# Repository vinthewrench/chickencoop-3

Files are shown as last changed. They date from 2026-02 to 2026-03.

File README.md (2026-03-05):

# Chicken Coop Controller 3.0

**Build your own automated, off-grid chicken coop door**

A minimal, ultra-reliable, battery-powered AVR controller that opens the door at sunrise, closes and locks it at sunset — completely offline, no sensors, no Wi-Fi, no cloud, no GPS.

Designed for a mobile pasture-raised coop that moves with cattle and sheep. Runs for months on a small 12 V battery (solar is only a top-up). Survives Arkansas mud, ice, dust, coyotes, and power failures.

Full 18-page design story, sunrise math, and lessons learned here:  
https://www.vinthewrench.com/<update this>

### Features

- True sunrise/sunset calculation using location + date (NO light sensor)
- Gravity-hung door with Progressive Automations PA-14 actuator
- Automatic locking bar (automotive-style actuator) to stop predators
- Manual override button with bi-color LED status
- Ultra-low sleep current (~355 µA) → months on a 7–22 Ah SLA/AGM battery
- One-time setup via serial console (no phone app or internet required)
- Two extra latching relays for electric fence or lights (zero holding current)
- Handles power failures, manual overrides, and reboots correctly
- Fully open-source (firmware + schematics + PCB)

### Licenses

- Firmware: MIT
- Hardware (schematics + PCB): CERN-OHL-P v2

You are free to study, modify, and build your own.

---

## How It Works

1. The DS3231M RTC wakes the ATmega1284P at the next event (sunrise or sunset).
2. Firmware calculates exact sunrise/sunset from latitude, longitude, and date.
3. If needed, it drives the door actuator and lock.
4. It sets the next alarm and goes back to deep sleep.

No drift, no false triggers from clouds, headlights, or moving the coop.

Manual button press overrides the schedule until the next natural event (sunrise/sunset). The system never fights you.

---

## Hardware

Custom 100 × 130 mm PCB (all through-hole friendly where possible).

### Major Components

| Component | Part | Notes |
| --- | --- | --- |
| MCU | ATmega1284P-PU (DIP-40) | 128 KB flash, easy ISP, repairable |
| RTC | DS3231M | Integrated resonator, temperature compensated |
| Door Actuator | Progressive Automations PA-14 | IP65, internal limits, stainless rod |
| Lock Actuator | 12 V automotive door lock | Pulses only (200–300 ms) |
| Motor Drivers | 2 × VNH7100BAS | 15 A H-bridges with thermal copper pours |
| 5 V Regulator | Pololu D24V22F5 | High efficiency, low quiescent current |
| Button | Illuminated bi-color switch | Red/Green status + override |
| Relays | 2 × DSP1-L2-DC12V | Latching (zero holding current) |
| Relay Driver | ULN2003A | Drives relays + optional loads |
| Optional Console | SparkFun DEV-15096 | USB-to-serial for setup (removable) |

Power: Single 12 V battery (SLA/AGM recommended). Direct 12 V to motors, regulated 5 V for logic.

---

## Firmware

Written in plain C for avr-gcc. No Arduino framework, no hidden magic.

Typical workflow:

```bash
cd firmware
make set-fuses
make
make flash          # or use your programmer
```

Full build system, clean targets, and EEPROM config handling included.

---

## Setup & Configuration

1. Flip the **CONFIG switch** to ON (this puts the controller into console mode).
2. Connect the optional SparkFun USB-to-serial module (or any 5 V TTL serial).
3. Open a terminal (38400 baud).
4. Set date/time, latitude, longitude, timezone offset, and schedule offsets.
5. Flip the **CONFIG switch** back to OFF when done.
6. Remove the module — the controller no longer needs it.

All settings stored in EEPROM. No re-configuration unless you move to a new location.

---

## Using the CONFIG Switch & Console

The physical **CONFIG switch** on the board toggles between normal low-power run mode and console configuration mode. When flipped to ON, the MCU stays awake, enables the serial console, and allows full setup/debug without sleeping. Flip back to OFF to resume automatic scheduling and deep sleep.

**Configuration steps:**

1. Flip CONFIG to ON.
2. Connect serial (38400 baud) and type commands.
3. Use `set` to configure, `event add` for schedules, `save` to commit.
4. Flip CONFIG to OFF.

**What you need to set (minimum for basic operation):**

- Date and time (`set date YYYY-MM-DD`, `set time HH:MM[:SS]`)
- Location (`set lat +/-DD.DDDD`, `set lon +/-DDD.DDDD`)
- Timezone (`set tz +/-HH`, `set dst on|off`)
- Events (`event add door on sunrise +0`, `event add door off sunset -15`, etc. for lock/relays)

**Key commands:**
| Command | What it does |
|---|---|
| `help` | List all commands |
| `config` | Show current settings |
| `set date YYYY-MM-DD` | Set date |
| `set time HH:MM[:SS]` | Set time (local) |
| `set lat +/-DD.DDDD` | Set latitude |
| `set lon +/-DDD.DDDD` | Set longitude |
| `set tz +/-HH` | Set timezone offset |
| `set dst on\|off` | Enable/disable DST |
| `event add ...` | Add door open/close events (sunrise/sunset or fixed time) |
| `save` | Commit everything to EEPROM |
| `schedule` | Show today’s full schedule |
| `solar` | Show sunrise/sunset |
| `door open\|close\|toggle` | Manual door test |
| `lock engage\|release` | Manual lock test |

Type `help` for full list. Changes are RAM-only until `save`.

---

## Repository Contents

- /firmware/ — AVR source + Makefile
- /hardware/ — KiCad schematics + PCB layout

---

## Typical Daily Workflow (after initial setup)

The controller just works. You walk out once a day to collect eggs.

---

## Links & Resources

- Full article: https://www.vinthewrench.com/<update>
- Buy the exact actuator: Progressive Automations PA-14 (PA-01-12-56-N-12VDC model)

Questions? Open an issue or find me on X @vinthewrench.

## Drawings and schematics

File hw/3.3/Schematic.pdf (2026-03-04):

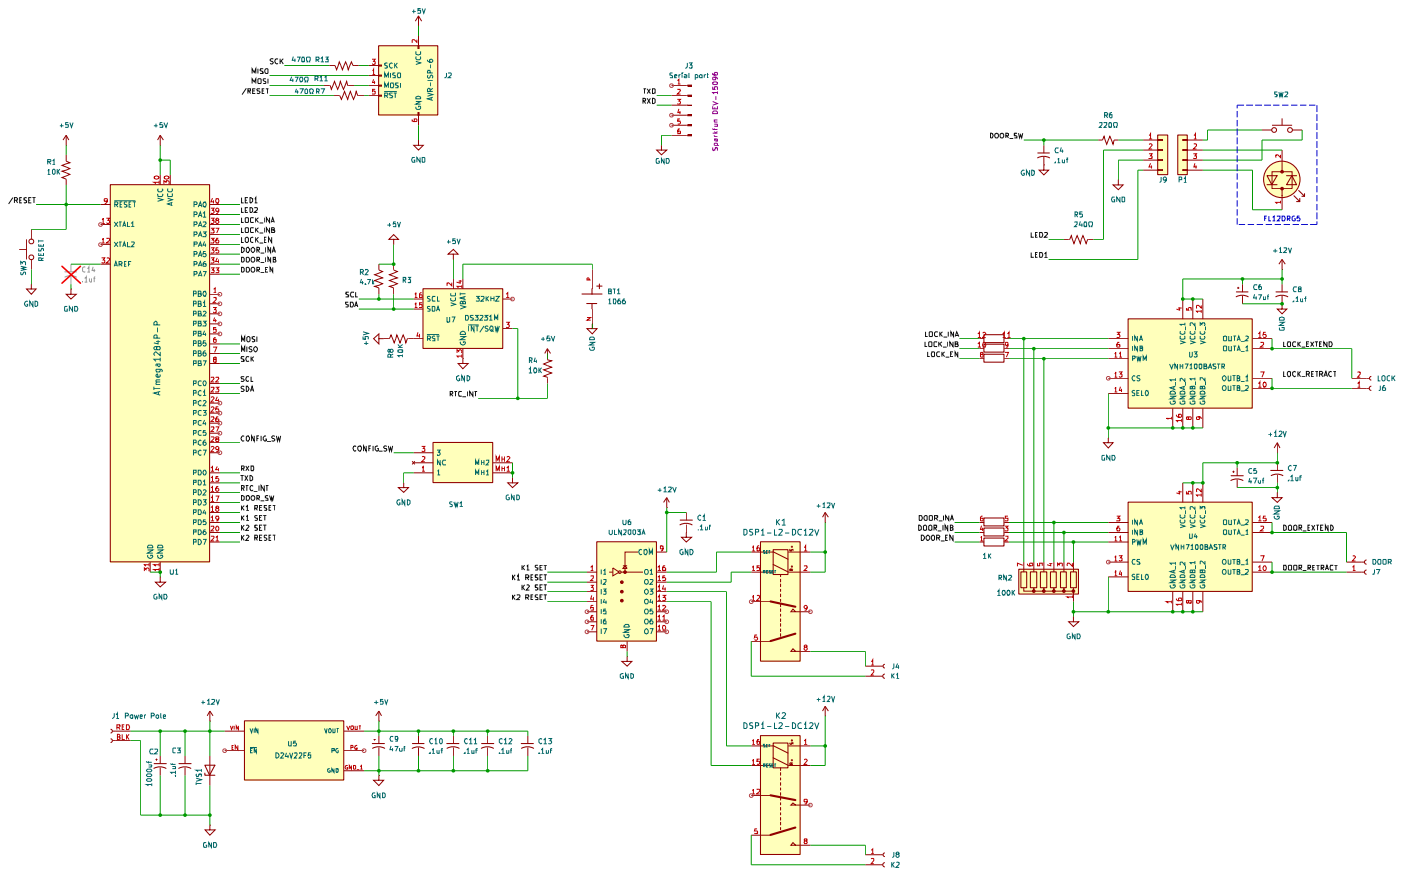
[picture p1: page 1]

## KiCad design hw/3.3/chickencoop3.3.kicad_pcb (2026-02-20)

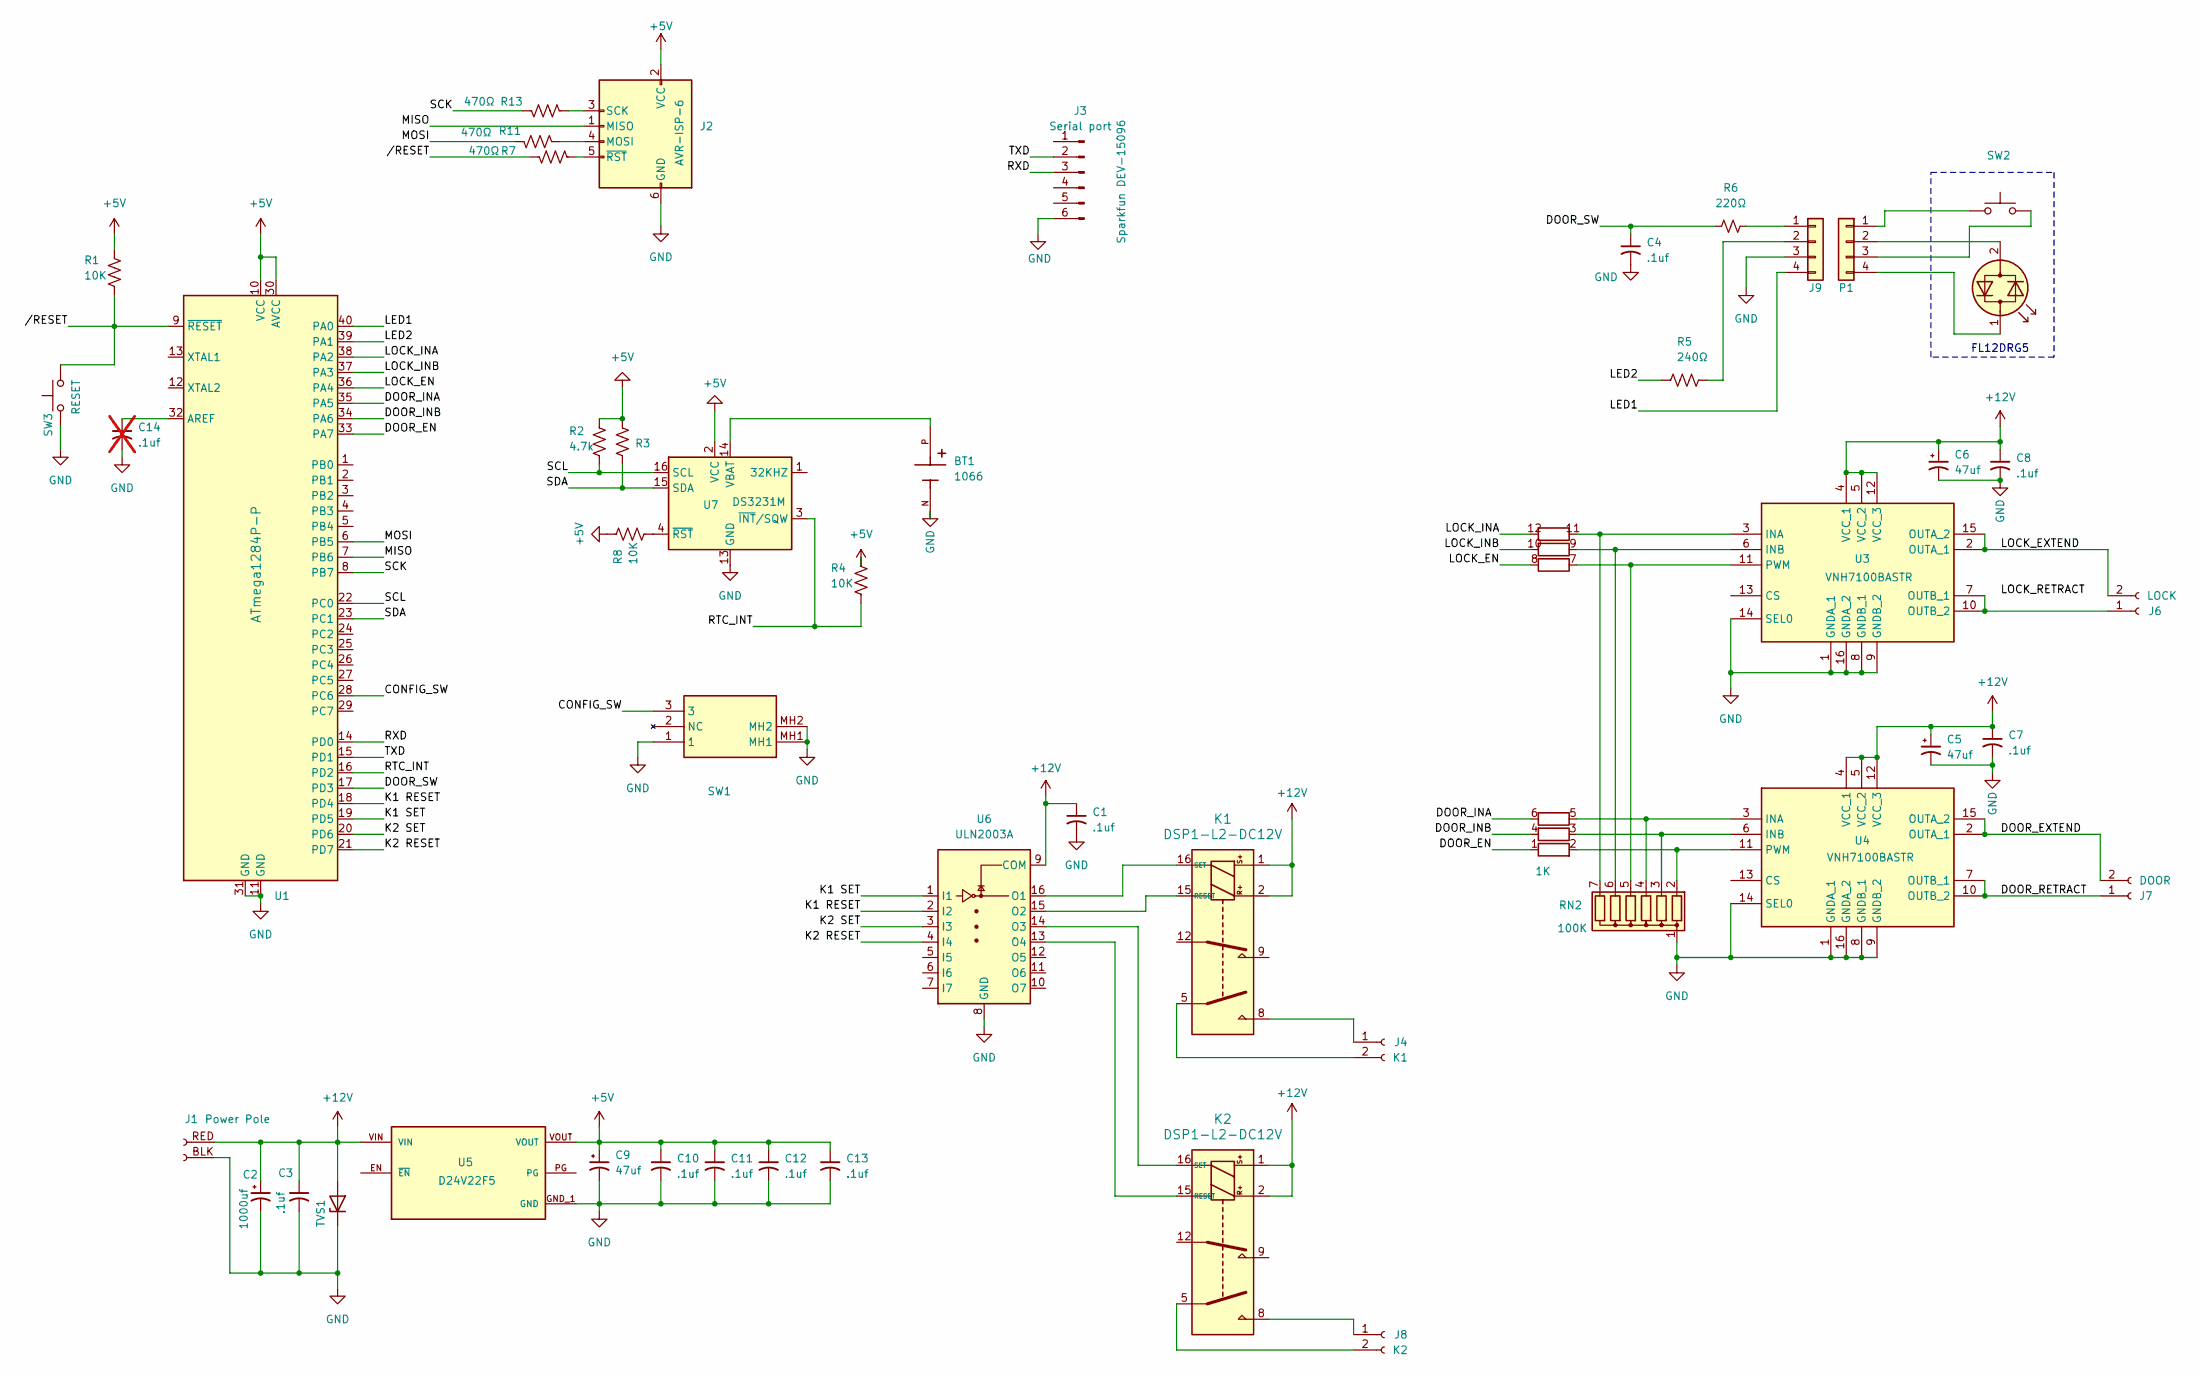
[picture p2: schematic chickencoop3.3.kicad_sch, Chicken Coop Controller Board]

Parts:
BT1: 1066; BAT_1066; PARTREV E
C1, C3, C4, C7, C8, C10, C11, C12, C13: .1uf; RCER71H104K0DBH03A
C2: 1000uf; CP_Radial_D10.0mm_P5.00mm
C5, C6, C9: 47uf; CP_Radial_D5.0mm_P2.00mm
C14: .1uf; RCER71H104K0DBH03A; not fitted
D1: LED_Dual_Bidirectional
J1: Power Pole; powerpole
J2: AVR-ISP-6; PinHeader_2x03_P2.54mm_Vertical
J3: Serial port; PinHeader_1x06_P2.54mm_Vertical
J4: K1; TerminalBlock_Phoenix_MKDS-1,5-2-5.08_1x02_P5.08mm_Horizont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
J6: LOCK; TerminalBlock_Phoenix_MKDS-1,5-2-5.08_1x02_P5.08mm_Horizont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
J7: DOOR; TerminalBlock_Phoenix_MKDS-1,5-2-5.08_1x02_P5.08mm_Horizont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
J8: K2; TerminalBlock_Phoenix_MKDS-1,5-2-5.08_1x02_P5.08mm_Horizont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
J9: Mini‑Fit Jr; Molex_Mini-Fit_Jr_5566-04A_2x02_P4.20mm_Vertical
K1, K2: DSP1-L2-DC12V
P1: Mini‑Fit Jr; Molex_Mini-Fit_Jr_5566-04A_2x02_P4.20mm_Vertical
R1, R4, R8: 10K; R_Axial_DIN0204_L3.6mm_D1.6mm_P7.62mm_Horizontal
R2: 4.7k; R_Axial_DIN0204_L3.6mm_D1.6mm_P7.62mm_Horizontal
R3: 4.7K; R_Axial_DIN0204_L3.6mm_D1.6mm_P7.62mm_Horizontal
R5: 240Ω; R_Axial_DIN0204_L3.6mm_D1.6mm_P7.62mm_Horizontal
R6: 220Ω; R_Axial_DIN0204_L3.6mm_D1.6mm_P7.62mm_Horizontal
R7, R11, R13: 470Ω; R_Axial_DIN0204_L3.6mm_D1.6mm_P7.62mm_Horizontal
RN2: 100K; R_Array_SIP7; Manufacturer_Part_Number 4607X-101-104LF
RN4: 1K; R_Array_SIP12; Manufacturer_Part_Number 4612X-102-102LF
SW1: SW_SPST; AS11CH; Mouser Part Number 633-AS11CH
SW2: SW_Push
SW3: RESET; SW_PUSH_6mm
TVS1: P6SMB18A; D_SMB_Handsoldering
U1: ATmega1284P-P; DIP-40_W15.24mm
U3, U4: VNH7100BASTR; SOIC127P600X175-16N; Manufacturer_Part_Number VNH7100BASTR; Mouser Part Number 511-VNH7100BASTR
U5: D24V22F5; MODULE_5V_2.5A_STEP-DOWN_D24V22F5; PARTREV 12 November 2015
U6: ULN2003A; DIP-16_W7.62mm
U7: DS3231M; SOIC-16W_7.5x10.3mm_P1.27mm

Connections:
+5V: C9.1, C10.1, C11.1, C12.1, C13.1, J2.2 (VCC), R1.1, R2.1, R3.1, R4.1, R8.1, U1.10 (VCC), U1.30 (AVCC), U5.VOUT, U7.2 (VCC)
+12V: C1.1, C2.1, C3.1, C5.1, C6.1, C7.1, C8.1, J1.RED, K1.1, K1.2, K2.1, K2.2, TVS1.2 (A), U3.4 (VCC_1), U3.5 (VCC_2), U3.12 (VCC_3), U4.4 (VCC_1), U4.5 (VCC_2), U4.12 (VCC_3), U5.VIN, U6.9 (COM)
/CONFIG_SW: SW1.3, U1.28 (PC6)
/DOOR_EN: RN4.1 (R1.1), U1.33 (PA7)
/DOOR_EXTEND: J7.2, U4.2 (OUTA_1), U4.15 (OUTA_2)
/DOOR_INA: RN4.6 (R3.2), U1.35 (PA5)
/DOOR_INB: RN4.4 (R2.2), U1.34 (PA6)
/DOOR_RETRACT: J7.1, U4.7 (OUTB_1), U4.10 (OUTB_2)
/DOOR_SW: C4.1, R6.1, U1.17 (PD3)
/K1 RESET: U1.18 (PD4), U6.2 (I2)
/K1 SET: U1.19 (PD5), U6.1 (I1)
/K2 RESET: U1.21 (PD7), U6.4 (I4)
/K2 SET: U1.20 (PD6), U6.3 (I3)
/LED1: J9.4, U1.40 (PA0)
/LED2: R5.1, U1.39 (PA1)
/LOCK_EN: RN4.8 (R4.2), U1.36 (PA4)
/LOCK_EXTEND: J6.2, U3.2 (OUTA_1), U3.15 (OUTA_2)
/LOCK_INA: RN4.12 (R6.2), U1.38 (PA2)
/LOCK_INB: RN4.10 (R5.2), U1.37 (PA3)
/MISO: J2.1 (MISO), U1.7 (PB6)
/MOSI: R11.1, U1.6 (PB5)
/RTC_INT: R4.2, U1.16 (PD2), U7.3 (~INT/SQW)
/RXD: J3.3, U1.14 (PD0)
/SCK: R13.1, U1.8 (PB7)
/SCL: R2.2, U1.22 (PC0), U7.16 (SCL)
/SDA: R3.2, U1.23 (PC1), U7.15 (SDA)
/TXD: J3.2, U1.15 (PD1)
//RESET: R1.2, R7.1, SW3.2, U1.9 (~RESET)
GND: BT1.N, C1.2, C2.2, C3.2, C4.2, C5.2, C6.2, C7.2, C8.2, C9.2, C10.2, C11.2, C12.2, C13.2, C14.2, J1.BLK, J2.6 (GND), J3.6, J9.3, RN2.1 (common), SW1.1, SW1.MH1, SW1.MH2, SW3.1, TVS1.1 (K), U1.11 (GND), U1.31 (GND), U3.1 (GNDA_1), U3.8 (GNDB_1), U3.9 (GNDB_2), U3.14 (SEL0), U3.16 (GNDA_2), U4.1 (GNDA_1), U4.8 (GNDB_1), U4.9 (GNDB_2), U4.14 (SEL0), U4.16 (GNDA_2), U5.GND_1 (GND), U5.GND_2 (GND), U6.8 (GND), U7.5 (GND), U7.6 (GND), U7.7 (GND), U7.8 (GND), U7.9 (GND), U7.10 (GND), U7.11 (GND), U7.12 (GND), U7.13 (GND)
unnamed: D1.1 (KA), P1.4
unnamed: D1.2 (AK), P1.2
unnamed: J2.4 (MOSI), R11.2
unnamed: J2.3 (SCK), R13.2
unnamed: J2.5 (~RST), R7.2
unnamed: J4.1, K1.8
unnamed: J4.2, K1.5
unnamed: J6.1, U3.7 (OUTB_1), U3.10 (OUTB_2)
unnamed: J8.1, K2.8
unnamed: J8.2, K2.5
unnamed: J9.1, R6.2
unnamed: J9.2, R5.2
unnamed: K1.15 (RESET), U6.15 (O2)
unnamed: K1.16 (SET), U6.16 (O1)
unnamed: K2.15 (RESET), U6.13 (O4)
unnamed: K2.16 (SET), U6.14 (O3)
unnamed: P1.1, SW2.1
unnamed: P1.3, SW2.2
unnamed: RN2.2 (R1), RN4.2 (R1.2), U4.11 (PWM)
unnamed: RN2.3 (R2), RN4.3 (R2.1), U4.6 (INB)
unnamed: RN2.4 (R3), RN4.5 (R3.1), U4.3 (INA)
unnamed: RN2.5 (R4), RN4.7 (R4.1), U3.11 (PWM)
unnamed: RN2.6 (R5), RN4.9 (R5.1), U3.6 (INB)
unnamed: RN2.7 (R6), RN4.11 (R6.1), U3.3 (INA)
unnamed: C14.1, U1.32 (AREF)
unnamed: BT1.P, U7.14 (VBAT)
unnamed: R8.2, U7.4 (~RST)

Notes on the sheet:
FL12DRG5

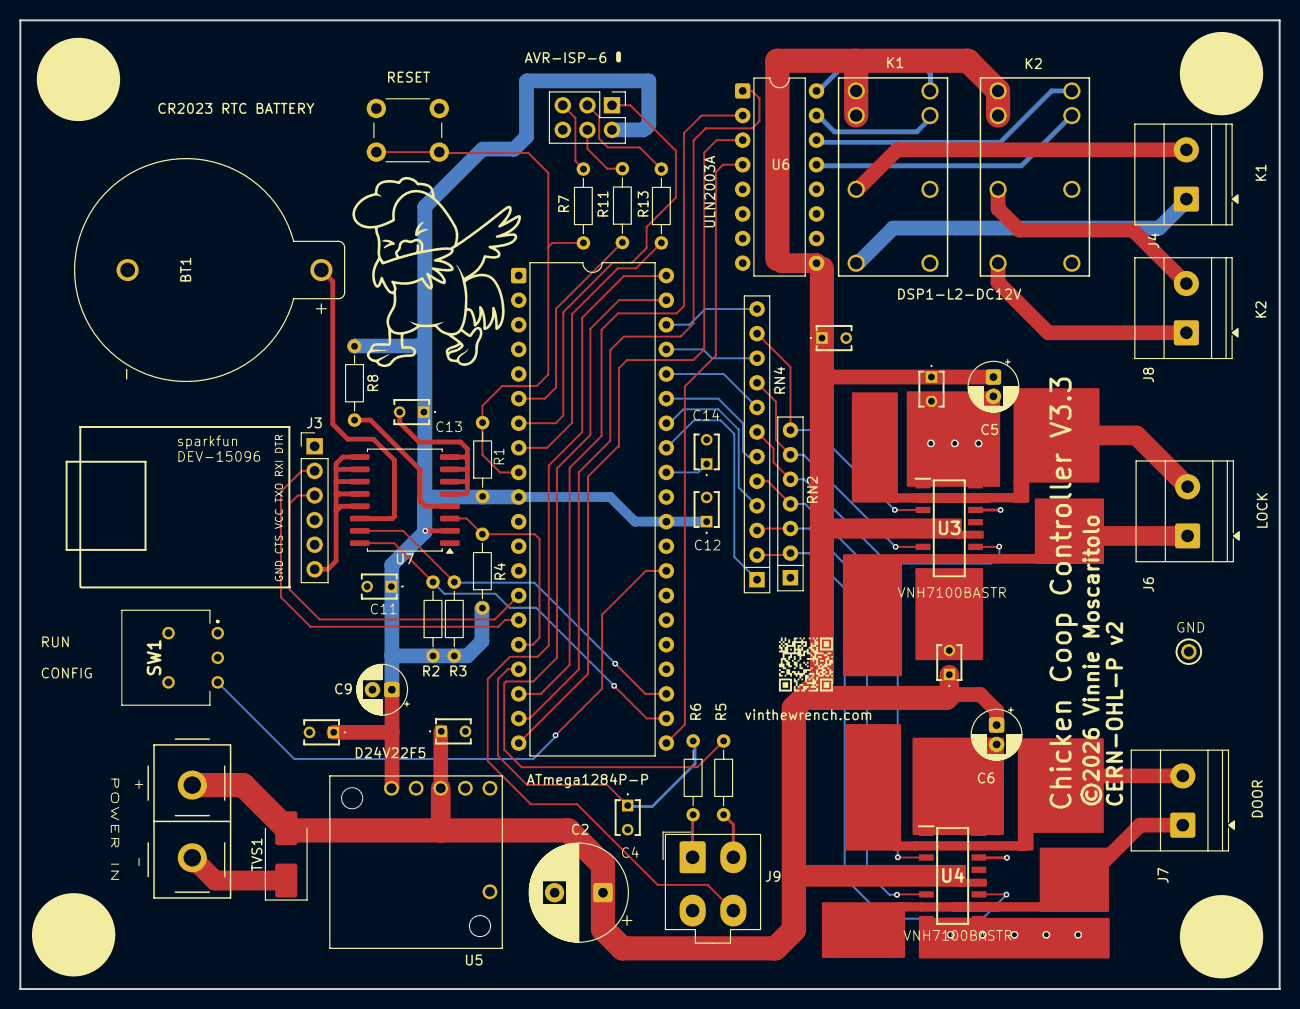
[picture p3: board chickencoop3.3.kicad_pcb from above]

Board: 2 copper layers, 130.0 x 100.0 mm, 47 parts (0 on the bottom side), 52 nets.

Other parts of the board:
TP3: GND; 5000

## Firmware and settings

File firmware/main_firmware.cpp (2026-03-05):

/*
 * main_firmware.cpp
 *
 * Chicken Coop Controller
 *
 * WAKE TRUTH:
 *   RTC INT → PD2 (INT0)
 *   LOW-level trigger
 *   SLEEP_MODE_PWR_DOWN
 *
 * Anything else is wrong.
 *
 * Time Model (UPDATED):
 *   - RTC returns UTC.
 *   - Scheduler runs in UTC.
 *   - Solar compute is requested in UTC (tz = 0).
 *   - TZ/DST must NOT affect scheduling here.
 *   - TZ/DST are console/UI concerns only.
 *
 * Updated: 2026-02-16
 */

#include <stdbool.h>
#include <stdint.h>
#include <util/delay.h>
#include <avr/io.h>
#include <avr/wdt.h>
#include <avr/interrupt.h>

#include "config.h"
#include "config_sw.h"

#include "console/console.h"
#include "console/mini_printf.h"

#include "uptime.h"
#include "rtc.h"
#include "solar.h"
#include "platform/uart.h"
#include "system_sleep.h"

/* DST/TZ must not be used for scheduling here. */
// #include "time_dst.h"

#include "scheduler.h"
#include "state_reducer.h"
#include "schedule_apply.h"

#include "devices/devices.h"
#include "devices/led_state_machine.h"
#include "devices/door_state_machine.h"

#include "platform/gpio_avr.h"
#include "platform/i2c.h"


/* ============================================================================
 * INT0 WAKE (PD2)
 * ========================================================================== */

ISR(INT0_vect)
{
    EIMSK &= (uint8_t)~(1u << INT0);
}

static volatile uint8_t g_door_event = 0;

ISR(INT1_vect)
{
    EIMSK &= (uint8_t)~(1u << INT1);
    g_door_event = 1u;
}


/* ============================================================================
 * TIME HELPERS
 * ========================================================================== */

static inline uint16_t minute_of_day(int h, int m)
{
    return (uint16_t)((uint16_t)h * 60u + (uint16_t)m);
}

static inline uint16_t next_minute(uint16_t now_min)
{
    return (uint16_t)((now_min + 1u) % 1440u);
}

static inline uint16_t strictly_future_minute(uint16_t now_min,
                                              uint16_t target_min)
{
    if (target_min <= now_min)
        return next_minute(now_min);
    return target_min;
}


/* ============================================================================
 * RESET CAUSE
 * ========================================================================== */

static uint8_t g_reset_flags;

static void reset_cause_capture_early(void)
{
    g_reset_flags = MCUSR;
    MCUSR = 0;
    wdt_disable();

    MCUCR |= _BV(JTD);
    MCUCR |= _BV(JTD);
}

static void reset_cause_debug_print(void)
{
    if (g_reset_flags & _BV(PORF))  mini_printf("RESET: Power On\n");
    if (g_reset_flags & _BV(BORF))  mini_printf("RESET: Brown-Out\n");
    if (g_reset_flags & _BV(WDRF))  mini_printf("RESET: Watchdog\n");
}


/* ============================================================================
 * MAIN
 * ========================================================================== */

int main(void)
{
    bool rtc_valid = false;

    reset_cause_capture_early();

    if (g_reset_flags & _BV(BORF)) {
        _delay_ms(50);
    }

    uart_init();
    uptime_init();
    coop_gpio_init();

    if (!i2c_init(100000)) {
        led_state_machine_init();
        led_state_machine_set(LED_BLINK, LED_RED);
        for (;;) {
            led_state_machine_tick(uptime_millis());
        }
    }

    rtc_init();

    rtc_valid = rtc_validate_at_boot();

    system_sleep_init();
    sei();

    device_init();
    scheduler_init();
    (void)config_load(&g_cfg);

    led_state_machine_set(LED_BLINK, LED_GREEN, 4);

    int last_y  = -1;
    int last_mo = -1;
    int last_d  = -1;

    uint16_t last_minute = 0xFFFF;
    uint32_t last_etag   = 0;

    struct solar_times sol;
    bool have_sol = false;

    bool in_config_mode = false;

    uint8_t  door_debounce_active   = 0;
    uint32_t door_debounce_start_ms = 0;

    int cached_y = 0, cached_mo = 0, cached_d = 0;
    int cached_h = 0, cached_m = 0, cached_s = 0;

    for (;;) {

        uint32_t now_ms = uptime_millis();
        device_tick(now_ms);

        /* ------------------------------------------------------
         * CONFIG switch
         * ------------------------------------------------------ */

        bool raw = config_sw_state();

        if (raw != in_config_mode) {

            _delay_ms(75);

            if (config_sw_state() == raw) {

                in_config_mode = raw;

                if (in_config_mode) {
                    console_init();
                    reset_cause_debug_print();
                } else {
                    mini_printf("Exiting console\n\n");
                    console_flush();
                    console_terminal_shutdown();
                }
            }
        }

        if (in_config_mode) {
            console_poll();
        }

        /* ------------------------------------------------------
         * Door ISR latch
         * ------------------------------------------------------ */

        if (g_door_event && !door_debounce_active) {
            g_door_event = 0u;
            door_debounce_active = 1u;
            door_debounce_start_ms = now_ms;
        }

        if (door_debounce_active) {
            if ((uint32_t)(now_ms - door_debounce_start_ms) >= 20u) {
                door_debounce_active = 0u;
                if (gpio_door_sw_is_asserted()) {
                    door_sm_toggle();
                }
            }
        }

        if (!gpio_door_sw_is_asserted() && !door_debounce_active) {
            EIFR  |= (uint8_t)(1u << INTF1);
            EIMSK |= (uint8_t)(1u << INT1);
        }

        /* ------------------------------------------------------
         * RTC required
         * ------------------------------------------------------ */

        if (rtc_time_is_set()) {
            if (!rtc_valid) rtc_valid = true;
        }
        else
        {
            led_state_machine_set(LED_BLINK, LED_RED);
            continue;
        }

        /* ------------------------------------------------------
         * Always refresh RTC (UTC authoritative)
         * ------------------------------------------------------ */

        rtc_get_time(&cached_y,
                     &cached_mo,
                     &cached_d,
                     &cached_h,
                     &cached_m,
                     &cached_s);

        uint16_t now_minute = minute_of_day(cached_h, cached_m);
        uint32_t cur_etag   = schedule_etag();

        bool minute_changed = (now_minute != last_minute);
        bool schedule_dirty = (cur_etag != last_etag);

        /* ------------------------------------------------------
         * On minute change or schedule change, run scheduler
         * ------------------------------------------------------ */

        if (minute_changed || schedule_dirty) {

            last_minute = now_minute;
            last_etag   = cur_etag;

            /* ---- Solar recompute if date changed ---- */

            if (cached_y != last_y ||
                cached_mo != last_mo ||
                cached_d != last_d) {

                have_sol = false;

                if (g_cfg.latitude_e4 != 0 ||
                    g_cfg.longitude_e4 != 0) {

                    double lat = (double)g_cfg.latitude_e4  / 10000.0;
                    double lon = (double)g_cfg.longitude_e4 / 10000.0;

                    /*
                     * Scheduling must be DST-invariant.
                     *
                     * Request solar times in UTC by forcing tz = 0.
                     * (Any TZ/DST adjustments belong in console/UI only.)
                     */
                    have_sol = solar_compute(
                        cached_y, cached_mo, cached_d,
                        lat, lon,
                        0,
                        &sol
                    );
                }

                scheduler_update_day(
                    cached_y, cached_mo, cached_d,
                    have_sol ? &sol : NULL,
                    have_sol
                );

                last_y  = cached_y;
                last_mo = cached_mo;
                last_d  = cached_d;
            }

            uint32_t midnight_epoch =
                rtc_epoch_from_ymdhms(
                    cached_y,
                    cached_mo,
                    cached_d,
                    0, 0, 0,
                    0,
                    false
                );

            /* ---- Apply schedule ---- */

            struct reduced_state rs;

            size_t used = 0;
            const Event *events = config_events_get(&used);

            if (events && used > 0) {

                state_reducer_run(
                    events,
                    MAX_EVENTS,
                    have_sol ? &sol : NULL,
                    now_minute,
                    midnight_epoch,
                    &rs
                );

                schedule_apply(&rs);
            }
        }

        /* ------------------------------------------------------
         * Sleep only in RUN mode
         * ------------------------------------------------------ */

        if (in_config_mode)
            continue;

        if (devices_busy() ||
            door_debounce_active ||
            g_door_event)
            continue;

        uint16_t next_min;
        uint16_t wake_min;

        if (scheduler_next_event_minute(now_minute, &next_min))
            wake_min = next_min;
        else
            wake_min = next_minute(now_minute);

        (void)rtc_alarm_set_minute_of_day(wake_min);
        system_sleep_until(wake_min);

        if (gpio_rtc_int_is_asserted())
            rtc_alarm_clear_flag();

        EIFR |= (uint8_t)((1u << INTF0) | (1u << INTF1));

        if (!gpio_rtc_int_is_asserted())
            EIMSK |= (uint8_t)(1u << INT0);

        if (!gpio_door_sw_is_asserted())
            EIMSK |= (uint8_t)(1u << INT1);
    }
}

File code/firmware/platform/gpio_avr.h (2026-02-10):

/*
 * gpio_avr.h
 *
 * Project: Chicken Coop Controller
 * Purpose: AVR GPIO pin definitions and low-level hardware mapping
 *
 * This header defines the canonical mapping between AVR GPIO pins
 * and physical hardware functions on the Chicken Coop Controller PCB.
 *
 * IMPORTANT DESIGN RULES:
 *  - All mappings in this file are LOCKED to the board schematic.
 *  - Do NOT rename, repurpose, or reassign any pin here unless
 *    the PCB schematic and layout are changed accordingly.
 *  - Higher-level code MUST treat these as hardware truth.
 *
 * SAFETY NOTE:
 *  - Several pins in this file control motors, relays, and solenoids.
 *  - Incorrect initialization or prolonged activation CAN damage hardware.
 *  - All outputs must be initialized to a known-safe OFF state at boot.
 *
 * Updated:
 *   (fill in date when pin mapping changes — not for code-only edits)
 */

#pragma once

/* --------------------------------------------------------------------------
 * Status LED Outputs
 * --------------------------------------------------------------------------
 *
 * These pins drive the front-panel red/green status LED through
 * external driver hardware.
 *
 * Naming convention:
 *  - LED_IN1 / LED_IN2 match the schematic net names.
 *  - Color association is documented for human clarity only.
 *
 * NOTE:
 *  - Do NOT change these names unless the hardware wiring changes.
 * -------------------------------------------------------------------------- */
 #define LED_IN1_BIT   PA1   /* RED   */
 #define LED_IN2_BIT   PA0   /* GREEN */

/* --------------------------------------------------------------------------
 * Door Motor H-Bridge Control (VNH7100BASTR)
 * --------------------------------------------------------------------------
 *
 * This H-bridge drives the main chicken coop door actuator.
 *
 * Electrical notes:
 *  - The door actuator includes internal end-of-travel limit switches.
 *  - Despite this, firmware MUST still enforce a maximum travel time
 *    as a fail-safe against wiring or switch failure.
 *
 * Pin behavior:
 *  - DOOR_EN   : Enables/disables the H-bridge (active HIGH)
 *  - DOOR_INA  : Direction control A
 *  - DOOR_INB  : Direction control B
 *
 * Reset behavior:
 *  - DOOR_EN MUST be driven LOW at boot.
 *  - INA/INB MUST be driven LOW at boot.
 *
 * -------------------------------------------------------------------------- */
/* DOOR_INA -> PF5 (physical pin 38) */
/* DOOR_INB -> PF6 (physical pin 37) */
/* DOOR_EN  -> PF7 (physical pin 36) */
#define DOOR_INA_BIT   PA5
#define DOOR_INB_BIT   PA6
#define DOOR_EN_BIT    PA7

/* --------------------------------------------------------------------------
 * Door Lock Actuator H-Bridge (VNH7100BASTR)
 * --------------------------------------------------------------------------
 *
 * This H-bridge drives the door LOCK actuator.
 *
 * CRITICAL SAFETY WARNING:
 *  - The lock actuator does NOT have end-of-travel limit switches.
 *  - It MUST be driven using a SHORT, FIXED-DURATION PULSE ONLY.
 *  - Continuous drive WILL overheat and destroy the actuator.
 *
 * Firmware requirements:
 *  - LOCK_EN MUST never be left asserted continuously.
 *  - A hard maximum pulse time (lock_pulse_ms) is mandatory.
 *  - Lock control must be edge-triggered, not state-held.
 *
 * JTAG NOTE:
 *  - LOCK_EN uses PF4, which is a JTAG pin by default.
 *  - Runtime JTAG disable is REQUIRED before driving this pin.
 * -------------------------------------------------------------------------- */
/* LOCK_INA -> PF0 */
/* LOCK_INB -> PF1 */
/* LOCK_EN  -> PF4 */
#define LOCK_INA_BIT   PA2
#define LOCK_INB_BIT   PA3
#define LOCK_EN_BIT    PA4

/* --------------------------------------------------------------------------
 * Latching Relay Outputs
 * --------------------------------------------------------------------------
 *
 * These pins drive a dual latching relay via external driver circuitry.
 *
 * Relay behavior:
 *  - SET and RESET are separate coils.
 *  - Coils must be pulsed briefly; they must NOT be held energized.
 *
 * Firmware requirements:
 *  - All relay outputs must default to OFF at boot.
 *  - Pulse duration must be limited in software.
 * -------------------------------------------------------------------------- */
#define RELAY1_SET_BIT    PD5
#define RELAY1_RESET_BIT  PD4
#define RELAY2_SET_BIT    PD6
#define RELAY2_RESET_BIT  PD7
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

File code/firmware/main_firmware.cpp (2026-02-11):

/*
 * main_firmware.cpp
 *
 * Chicken Coop Controller
 *
 * WAKE TRUTH:
 *   RTC INT → PD2 (INT0)
 *   LOW-level trigger
 *   SLEEP_MODE_PWR_DOWN
 *
 * Anything else is wrong.
 *
 * Updated: 2026-02-08
 */

#include <stdbool.h>
#include <stdint.h>
#include <util/delay.h>
#include <avr/io.h>
#include <avr/wdt.h>
#include <avr/interrupt.h>

#include "config.h"
#include "config_sw.h"

#include "console/console.h"
#include "console/mini_printf.h"

#include "uptime.h"
#include "rtc.h"
#include "solar.h"
#include "platform/uart.h"
#include "system_sleep.h"

#include "time_dst.h"

#include "scheduler.h"
#include "state_reducer.h"
#include "schedule_apply.h"

#include "devices/devices.h"
#include "devices/led_state_machine.h"
#include "devices/door_state_machine.h"

#include "platform/gpio_avr.h"
#include "platform/i2c.h"


/* ============================================================================
 * INT0 WAKE (PD2)
 * ========================================================================== */
 /*
  * INT0 ISR
  *
  * One-shot mask so we don't re-enter while
  * RTC INT line is still held low (AF not cleared yet).
  */
 ISR(INT0_vect)
 {
     EIMSK &= (uint8_t)~(1u << INT0);
 }

 static volatile uint8_t g_door_event = 0;

 ISR(INT1_vect)
 {
     /* Mask INT1 immediately (one-shot) */
        EIMSK &= (uint8_t)~(1u << INT1);

        /* Latch event */
        g_door_event = 1u;
 }


// static void rtc_wake_init_pd2(void)
// {
//     /* PD2 input */
//     DDRD  &= (uint8_t)~(1u << PD2);

//     /* External pull-up exists. Leave internal OFF. */
//     PORTD &= (uint8_t)~(1u << PD2);

//     /* LOW-level trigger required for PWR_DOWN wake */
//     EICRA &= (uint8_t)~((1u << ISC01) | (1u << ISC00));

//     /* Clear any stale flag */
//     EIFR  |= (uint8_t)(1u << INTF0);

//     /* Enable INT0 */
//     EIMSK |= (uint8_t)(1u << INT0);
// }

/* ============================================================================
 * TIME HELPERS
 * ========================================================================== */

static inline uint16_t minute_of_day(int h, int m)
{
    return (uint16_t)((uint16_t)h * 60u + (uint16_t)m);
}

static inline uint16_t next_minute(uint16_t now_min)
{
    return (uint16_t)((now_min + 1u) % 1440u);
}

static inline uint16_t strictly_future_minute(uint16_t now_min,
                                              uint16_t target_min)
{
    if (target_min <= now_min)
        return next_minute(now_min);
    return target_min;
}



static uint8_t g_reset_flags;

static void reset_cause_capture_early(void)
{
    g_reset_flags = MCUSR;
    MCUSR = 0;          /* clear flags immediately */
    wdt_disable();      /* if WDT ever enabled, keep boot deterministic */

    /* Disable JTAG immediately (double write required) */
    MCUCR |= _BV(JTD);
    MCUCR |= _BV(JTD);

}

static void reset_cause_debug_print(void)
{
    /* Optional, but useful while you are validating BOD behavior */
     if (g_reset_flags & _BV(PORF))  mini_printf("RESET: Power On\n");
//    if (g_reset_flags & _BV(EXTRF)) mini_printf(" EXT");
    if (g_reset_flags & _BV(BORF))  mini_printf("RESET: Brown-Out\n");
    if (g_reset_flags & _BV(WDRF))  mini_printf("RESET: Watchdog\n");
 }


/* ============================================================================
 * MAIN
 * ========================================================================== */

int main(void)
{
    reset_cause_capture_early();

     /* If brown-out reset, allow rails + peripherals to settle */
     if (g_reset_flags & _BV(BORF)) {
         _delay_ms(50);
     }


    uart_init();

    if (!i2c_init(100000)) {
        mini_printf("I2C init failed\n");
        while (1);
    }

    uptime_init();
    rtc_init();

    coop_gpio_init();

    /* INT0 wake path (PD2) */
    system_sleep_init();

    sei();

    device_init();
    scheduler_init();

    (void)config_load(&g_cfg);

    /* ----------------------------------------------------------
     * CONFIG MODE
     * ---------------------------------------------------------- */

    static bool config_consumed = false;

    if (config_sw_state() && !config_consumed) {

        config_consumed = true;

        console_init();

        reset_cause_debug_print();   /* <-- add this here */

        if (!rtc_time_is_set())
            led_state_machine_set(LED_BLINK, LED_RED);

        while (!console_should_exit()) {
            console_poll();
            device_tick(uptime_millis());


            ///-----------
            /* Re-arm INT1 only when door switch is released */
            EIFR |= (uint8_t)(1u << INTF1);
            if (!gpio_door_sw_is_asserted()) {
                EIMSK |= (uint8_t)(1u << INT1);
            }

            /* ------------------------------------------------------
             * Manual Door Switch Event
             * ------------------------------------------------------ */
            if (g_door_event) {

                g_door_event = 0u;

                /* Confirm switch still asserted (debounce) */
                _delay_ms(20);


                if (gpio_door_sw_is_asserted()) {
                   door_sm_toggle();
                }
            }

            ///---


        }
    }


    /* ----------------------------------------------------------
     * RUN MODE requires valid RTC
     * ---------------------------------------------------------- */
    if (!rtc_time_is_set()) {
        led_state_machine_set(LED_BLINK, LED_RED);
        for (;;) {
            device_tick(uptime_millis());
        }
    }



    /* Healthy boot pulse */
    led_state_machine_set(LED_ON, LED_GREEN);
    {
        uint32_t t0 = uptime_millis();
        while ((uint32_t)(uptime_millis() - t0) < 1000u)
            device_tick(uptime_millis());
    }
    led_state_machine_set(LED_OFF, LED_GREEN);

    /* ----------------------------------------------------------
     * Scheduler state
     * ---------------------------------------------------------- */
    uint16_t last_minute = 0xFFFF;
    uint32_t last_etag   = 0;

    int last_y  = -1;
    int last_mo = -1;
    int last_d  = -1;

    struct solar_times sol;
    bool have_sol = false;

    /* ----------------------------------------------------------
     * MAIN LOOP
     * ---------------------------------------------------------- */
    for (;;) {

    /* Always clear AF first.
           This releases INT line high again. */
        rtc_alarm_clear_flag();

        /* Re-arm INT0 after AF cleared */
        EIFR  |= (uint8_t)(1u << INTF0);
        EIMSK |= (uint8_t)(1u << INT0);

        /* Re-arm INT1 only when door switch is released */
        EIFR |= (uint8_t)(1u << INTF1);
        if (!gpio_door_sw_is_asserted()) {
            EIMSK |= (uint8_t)(1u << INT1);
        }

        /* ------------------------------------------------------
         * Manual Door Switch Event
         * ------------------------------------------------------ */
        if (g_door_event) {
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

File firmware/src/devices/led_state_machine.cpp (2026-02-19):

/*
 * led_state_machine.cpp
 *
 * Project: Chicken Coop Controller
 * Purpose: Door status LED state machine
 *
 * Notes:
 *  - Non-blocking at the state-machine level
 *  - Software PWM carrier is driven by repeated door_led_tick() calls
 *  - Pulse envelope is rate-limited for smooth breathing
 *
 * Extended:
 *  - Blink/Pulse may run finite number of cycles
 *  - count = 0 → infinite
 *  - count > 0 → run exactly N cycles then auto-off
 */

#include "led_state_machine.h"
#include "door_led.h"

#include <stdint.h>
#include <stdbool.h>

/* --------------------------------------------------------------------------
 * Timing
 * -------------------------------------------------------------------------- */

#define BLINK_PERIOD_MS   250u
#define PULSE_PERIOD_MS  2800u
#define PWM_TICKS_PER_MS  128u

/* --------------------------------------------------------------------------
 * Internal state
 * -------------------------------------------------------------------------- */

static led_mode_t  g_mode  = LED_OFF;
static led_color_t g_color = LED_GREEN;

/* Optional finite-cycle support */
static uint16_t g_cycles_remaining = 0;   /* 0 = infinite */
static uint16_t g_cycle_counter    = 0;   /* counts completed cycles */

static uint32_t g_blink_t0_ms = 0;
static bool     g_led_on      = false;

/* Pulse timing (in PWM ticks) */
static uint32_t g_pulse_last_ticks = 0;
static uint8_t  g_pulse_step       = 0;
static uint32_t g_pwm_ticks        = 0;
static uint32_t g_pulse_err        = 0;

static int8_t g_pulse_dir = -1;   /* -1 = decaying, +1 = rising */

/* --------------------------------------------------------------------------
 * Perceptual breathing envelopes
 * -------------------------------------------------------------------------- */

 static const uint8_t pulse_lut_green[] = {
       1,  1,  2,  3,  5,  8, 12, 17,
      23, 30, 38, 47, 57, 68, 80, 93,
     107,122,138,155,173,192,212,233,255,
     233,212,192,173,155,138,122,107,
      93, 80, 68, 57, 47, 38, 30, 23,
      17, 12,  8,  5,  3,  2,  1
 };

 static const uint8_t pulse_lut_red[] = {
       1,  2,  4,  7, 11, 16, 22, 29,
      37, 46, 56, 67, 79, 92,106,121,
     137,154,172,191,211,232,248,255,
     248,232,211,191,172,154,137,121,
     106, 92, 79, 67, 56, 46, 37, 29,
      22, 16, 11,  7,  4,  2,  1,
 };

#define PULSE_STEPS_GREEN ((uint8_t)sizeof(pulse_lut_green))
#define PULSE_STEPS_RED   ((uint8_t)sizeof(pulse_lut_red))

/* --------------------------------------------------------------------------
 * Helpers
 * -------------------------------------------------------------------------- */

static inline void led_apply(bool on, uint8_t duty)
{
    if (!on) {
        door_led_off();
        return;
    }

    if (g_color == LED_GREEN)
        door_led_green_pwm(duty);
    else
        door_led_red_pwm(duty);
}

static void door_led_pwm_service(uint32_t now_ms)
{
    static uint32_t last_ms = 0;

    uint32_t elapsed = now_ms - last_ms;
    if (elapsed == 0)
        return;

    last_ms = now_ms;

    uint32_t ticks = elapsed * PWM_TICKS_PER_MS;

    const uint32_t MAX_TICKS = 10u * PWM_TICKS_PER_MS;
    if (ticks > MAX_TICKS)
        ticks = MAX_TICKS;

    while (ticks--) {
        door_led_tick();
        g_pwm_ticks++;
    }
}

/* --------------------------------------------------------------------------
 * Public API
 * -------------------------------------------------------------------------- */

/**
 * @brief Initialize LED state machine.
 */
void led_state_machine_init(void)
{
    g_mode              = LED_OFF;
    g_color             = LED_GREEN;
    g_cycles_remaining  = 0;
    g_cycle_counter     = 0;

    g_blink_t0_ms       = 0;
    g_led_on            = false;

    g_pulse_last_ticks  = 0;
    g_pulse_step        = 0;
    g_pwm_ticks         = 0;
    g_pulse_err         = 0;

    door_led_init();
    door_led_off();
}


/**
 * @brief Set LED mode with optional finite cycle count.
 *
 * @param mode   LED mode
 * @param color  LED color
 * @param count  Number of cycles (0 = infinite)
 */
 void led_state_machine_set(led_mode_t mode,
                            led_color_t color,
                            uint16_t count)
 {
     g_mode             = mode;
     g_color            = color;
     g_cycles_remaining = count;
     g_cycle_counter    = 0;

     g_blink_t0_ms      = 0;
     g_led_on           = false;

     g_pulse_last_ticks = 0;
     g_pulse_step       = 0;
     g_pulse_err        = 0;
     g_pulse_dir        = -1;   /* default */

     if (mode == LED_OFF) {
         door_led_off();
         return;
     }

     if (mode == LED_ON) {
         g_led_on = true;
         led_apply(true, 255);
         return;
     }

     if (mode == LED_PULSE) {

         g_led_on = true;

         /* Start at peak and decay */
         if (color == LED_GREEN)
             g_pulse_step = PULSE_STEPS_GREEN - 1;
         else
             g_pulse_step = PULSE_STEPS_RED - 1;

         g_pulse_last_ticks = g_pwm_ticks;
         g_pulse_err        = 0;
         g_pulse_dir        = -1;   /* decay first */
     }
 }

/**
 * @brief Backward-compatible overload (infinite cycles).
 */
void led_state_machine_set(led_mode_t mode,
                           led_color_t color)
{
    led_state_machine_set(mode, color, 0);
}

bool led_state_machine_is_on(void)
{
    return g_led_on;
}
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

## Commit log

2025-12-30 CLI: finalize explicit event grammar, persistence, and resolver
    - Make config the sole authoritative event store
    - Add explicit solar/civil anchors (sunrise/sunset, dawn/dusk)
    - Support implicit midnight for bare HH:MM
    - Fix command arg limits for extended grammar
    - Add # comment stripping before tokenization
    - Remove device-invented default events (door)
    - Keep resolver pure and stateless
    - Verify save/reload parity on host and firmware
    [coop.cfg]
2025-12-31 Stop tracking coop.cfg
    [coop.cfg]
2026-01-01 cleaning up devices
2026-01-02 Bring-up checkpoint: door/lock HW abstraction, host parity, console test hooks
    - Introduce door_hw / lock_hw hardware abstraction using INA/INB/EN model
    - Add AVR implementations for door and lock H-bridge control
    - Add host-side equivalents for hardware simulation
    - Keep console test hooks (door open/close, lock engage/release) as temporary stubs
    - Device path (door_device) drives hardware directly for now
    - Preserve separation between device intent and console imperative testing
    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
2026-01-08 Refactor door control into explicit state machines; integrate lock and LED logic
    - Introduced platform-agnostic door and lock state machines
    - Enforced unlock-before-move and lock-after-close sequencing
    - Added LED state machine with OFF / ON / BLINK / BREATHE-PULSE modes
    - Centralized door motion transitions to drive LED behavior deterministically
    - Removed hardware timing and safety logic from door device layer
    - Added host-side hardware stubs for visibility and debugging
    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
2026-02-04 Simplify door lock: remove lock state machine, add bounded blocking lock pulse
    - Replace async lock state machine with blocking door_lock driver
    - Enforce hard max lock pulse time at hardware layer
    - Simplify door state machine sequencing (unlock → move → settle → lock)
    - Remove redundant lock device and host/AVR abstractions
    - Preserve host/firmware parity
    [console_cmds.cpp, door_lock_avr.cpp]
2026-02-05 Fix RTC issues and remove uptime-based time staging
    [console_cmds.cpp, rtc.cpp]
2026-02-06 RTC epoch + EESAVE fuse preserve + mini_printf 32-bit support
2026-02-09 LED action takes count argument -- sleep test works
2026-02-11 BOD and RTC fixes
    [main_firmware.cpp, rtc.cpp]
2026-02-11 minimal door button hookup in console mode
2026-02-17 FIX times display - always show local
    [console_cmds.cpp]
2026-02-19 prettier LED pulse
2026-02-19 relay_device: add manual override concept using UTC timestamp to suppress stale schedule events
2026-02-20 updated HW to use DS3231
    [chickencoop3.3.kicad_pcb, chickencoop3.3.kicad_sch]
2026-03-02 switched RTC to DS3231
2026-03-04 added schematic
2026-03-05 Fix scheduler next-event logic and pass current minute
    scheduler_next_event_minute() previously returned the earliest event
    minute in the table regardless of current time. This caused incorrect
    behavior when querying the next event from the console or sleep logic.
    The scheduler now receives the current UTC minute-of-day and returns
    the earliest event strictly after the current time. If no future event
    exists today, it wraps to the earliest event tomorrow.
    Changes:
    - scheduler_next_event_minute() now takes
    - scheduler scans sparse event table and ignores past events
    - wrap-to-tomorrow logic added when no future event exists today
    - firmware main loop updated to pass now_minute
    - console co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
    [diff.txt]
2026-03-05 clean garbage
    [diff.txt]
2026-06-02 Ignore KiCad footprint cache

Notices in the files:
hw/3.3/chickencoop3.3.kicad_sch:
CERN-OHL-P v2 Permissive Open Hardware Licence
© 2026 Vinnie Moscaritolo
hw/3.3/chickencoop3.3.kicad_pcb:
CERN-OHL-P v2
